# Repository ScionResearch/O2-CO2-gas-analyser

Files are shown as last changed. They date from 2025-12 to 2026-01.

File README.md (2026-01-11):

# O2-CO2 Gas Analyser

A precision gas analysis system built on the SAMD21 microcontroller platform, featuring simultaneous O2 and CO2 measurement with temperature-controlled sampling chamber and Modbus RTU communication.

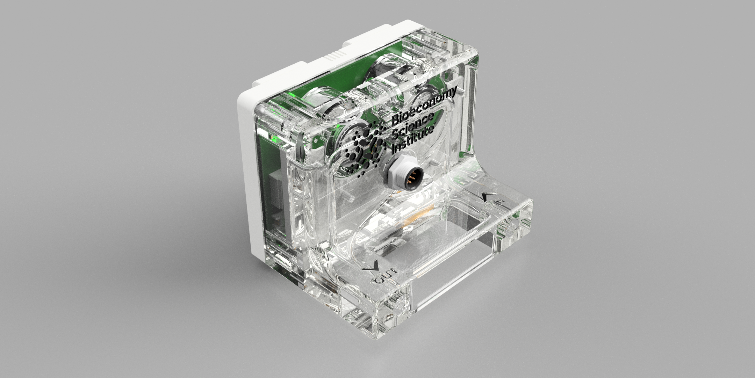
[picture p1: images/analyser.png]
Gas Analyser


## Features

- **O2 Measurement**: SGX 4OX electrochemical oxygen sensor with temperature compensation
- **CO2 Measurement**: SGX INIR2-CD100 infrared CO2 sensor (0-10% range)
- **Temperature Control**: PID-controlled heater maintaining stable measurement conditions
- **Humidity Sensing**: Sensirion SHT4x for gas temperature and relative humidity
- **Communication**: Modbus RTU over RS-485 with configurable baud rate and addressing
- **Status Monitoring**: Comprehensive status register for system health monitoring
- **Calibration**: In-field zero and span calibration for both O2 and CO2 sensors

## Hardware

- **MCU**: SAMD21-based custom board (gas_analyser_m0)
- **O2 Sensor**: SGX 4OX (galvanic cell, 70-130 uA in air)
- **CO2 Sensor**: SGX INIR2-CD100 (NDIR, UART interface)
- **Temperature/Humidity**: Sensirion SHT40
- **Heater**: PWM-controlled with NTC thermistor feedback
- **Interface**: RS-485 with optional 120 Ohm termination

---

## Modbus RTU Interface

### Default Communication Settings

| Parameter | Default Value |
|---|---|
| Slave ID | 100 |
| Baud Rate | 9600 |
| Data Bits | 8 |
| Parity | None |
| Stop Bits | 1 |

### Supported Function Codes

| Function Code | Description |
|---|---|
| 03 | Read Holding Registers |
| 04 | Read Input Registers |
| 06 | Write Single Holding Register |
| 16 | Write Multiple Holding Registers |

---

## Register Definitions

### Input Registers (Function Code 04) - Read Only

Input registers contain sensor measurements. All floating-point values are stored as IEEE 754 single-precision (32-bit) spanning two consecutive 16-bit registers in big-endian order.

| Address | Name | Type | Unit | Description |
|---|---|---|---|---|
| 0-1 | O2percent | float | % | Oxygen concentration |
| 2-3 | CO2percent | float | % | CO2 concentration (as percentage) |
| 4-5 | CO2ppm | float | ppm | CO2 concentration (as ppm) |
| 6-7 | gasTempC | float | C | Gas stream temperature (SHT40) |
| 8-9 | gasRH | float | %RH | Gas stream relative humidity |
| 10-11 | gasAH | float | g/m3 | Absolute humidity |
| 12-13 | gasVP | float | Pa | Vapour pressure |
| 14-15 | ambTempC | float | C | Ambient temperature (NTC) |
| 16-17 | heatTempC | float | C | Heater block temperature (NTC) |

### Holding Registers (Function Code 03/06/16) - Read/Write

Holding registers contain configuration and calibration parameters. Changes are automatically saved to non-volatile memory.

| Address | Name | Type | Unit | Description |
|---|---|---|---|---|
| 0-1 | status | uint32 | - | System status register (see below) |
| 2 | modbusSlaveID | uint16 | - | Modbus slave address (2-246) |
| 3 | modbusBaudrate | uint16 | x10 | Baud rate / 10 (e.g., 960 = 9600) |
| 4 | modbusStopBits | uint16 | - | Stop bits (1-3) |
| 5 | modbusParity | uint16 | - | Parity: 1=Even, 2=Odd, 3=None |
| 6 | modbus120Rterm | uint16 | - | RS-485 termination: 0=Off, 1=On |
| 7 | reserved1 | uint16 | - | Reserved for future use |
| 8 | O2SetZeroPoint | uint16 | - | Write 1 to start O2 zero cal |
| 9 | CO2SetZeroPoint | uint16 | ppm | CO2 zero cal reference (1-4999) |
| 10-11 | O2SetXPoint | float | % | O2 span cal point (10.0-25.0) |
| 12-13 | CO2SetXPoint | float | ppm | CO2 span cal point (300-50000) |
| 14-15 | heaterKp | float | - | PID proportional gain |
| 16-17 | heaterKi | float | - | PID integral gain |
| 18-19 | heaterKd | float | - | PID derivative gain |
| 20-21 | heaterMaxI | float | - | PID integral limit (0-255) |
| 22-23 | heaterSetpointC | float | C | Heater setpoint (20.0-50.0) |
| 24-25 | heaterMinAmbientDeltaC | float | C | Min delta above ambient (0-20) |

#### Valid Baud Rate Values

| Register Value | Actual Baud Rate |
|---|---|
| 960 | 9600 |
| 1920 | 19200 |
| 3840 | 38400 |
| 5760 | 57600 |
| 11520 | 115200 |

---

## Status Register

The status register (holding registers 0-1) is a 32-bit value containing system health information. Each 4-bit nibble represents a different subsystem.

### Status Register Bit Layout

```
Bits 31-24       23-20      19-16               15-12       11-8          7-4    3-0
     [WDT Count] [Amb Temp] [Gas Temp/Humidity] [Heater]    [CO2 Sensor]  [O2]   [System]
```

### Subsystem Status Definitions

#### System Status (Bits 3-0)
| Value | Meaning |
|---|---|
| 0x01 | System OK |
| 0x02 | WDT Reset Occurred |
| 0x03 | System OK + WDT Reset History |

#### O2 Sensor Status (Bits 7-4)
| Value | Meaning |
|---|---|
| 0x01 | Sensor OK |
| 0x02 | Reading too high (>25%) |
| 0x04 | Sensor not connected (<1%) |

#### CO2 Sensor Status (Bits 11-8)
| Value | Meaning |
|---|---|
| 0x01 | Sensor OK |
| 0x02 | Sensor not connected (no data) |
| 0x04 | Sensor communication error |

#### Heater Status (Bits 15-12)
| Value | Meaning |
|---|---|
| 0x01 | Temperature stable |
| 0x02 | Temperature unstable (>0.2C from setpoint) |
| 0x04 | Temperature sensor error |

#### Gas Temperature/Humidity Status (Bits 19-16)
| Value | Meaning |
|---|---|
| 0x01 | Sensor OK |
| 0x02 | Sensor error |

#### Ambient Temperature Status (Bits 23-20)
| Value | Meaning |
|---|---|
| 0x01 | Sensor OK |
| 0x02 | Sensor error |

#### WDT Reset Count (Bits 27-24)
Contains the number of watchdog timer resets since last EEPROM clear (0-255, saturates at 255).

---

## Usage Examples

### Reading Sensor Values (Python with pymodbus)

```python
from pymodbus.client import ModbusSerialClient
import struct

# Connect to the analyser
client = ModbusSerialClient(
    port='COM3',
    baudrate=9600,
    parity='N',
    stopbits=1,
    bytesize=8,
    timeout=1
)
client.connect()

SLAVE_ID = 100

def read_float(client, address, slave_id):
    """Read a 32-bit float from two consecutive input registers."""
    result = client.read_input_registers(address, 2, slave=slave_id)
    if result.isError():
        return None
    # Combine two 16-bit registers into a 32-bit float (big-endian)
    raw = (result.registers[0] << 16) | result.registers[1]
    return struct.unpack('>f', struct.pack('>I', raw))[0]

# Read all sensor values
o2_percent = read_float(client, 0, SLAVE_ID)
co2_percent = read_float(client, 2, SLAVE_ID)
co2_ppm = read_float(client, 4, SLAVE_ID)
gas_temp = read_float(client, 6, SLAVE_ID)
gas_rh = read_float(client, 8, SLAVE_ID)
heater_temp = read_float(client, 16, SLAVE_ID)

print(f"O2: {o2_percent:.2f}%")
print(f"CO2: {co2_ppm:.0f} ppm ({co2_percent:.3f}%)")
print(f"Gas Temperature: {gas_temp:.1f}C")
print(f"Gas RH: {gas_rh:.1f}%")
print(f"Heater Temperature: {heater_temp:.1f}C")

client.close()
```

### Parsing the Status Register

```python
def parse_status(client, slave_id):
    """Read and parse the status register."""
    result = client.read_holding_registers(0, 2, slave=slave_id)
    if result.isError():
        return None
    
    status = (result.registers[0] << 16) | result.registers[1]
    
    # Extract each nibble
    system_status = status & 0x0F
    o2_status = (status >> 4) & 0x0F
    co2_status = (status >> 8) & 0x0F
    heater_status = (status >> 12) & 0x0F
    gas_th_status = (status >> 16) & 0x0F
    amb_temp_status = (status >> 20) & 0x0F
    wdt_count = (status >> 24) & 0xFF
    
    # Interpret statuses
    status_names = {
        'system': {0x01: 'OK', 0x02: 'WDT Reset', 0x03: 'OK (WDT history)'},
        'o2': {0x01: 'OK', 0x02: 'Too High', 0x04: 'Not Connected'},
        'co2': {0x01: 'OK', 0x02: 'Not Connected', 0x04: 'Error'},
        'heater': {0x01: 'Stable', 0x02: 'Unstable', 0x04: 'Sensor Error'},
        'gas_th': {0x01: 'OK', 0x02: 'Error'},
        'amb_temp': {0x01: 'OK', 0x02: 'Error'}
    }
    
    print(f"System: {status_names['system'].get(system_status, 'Unknown')}")
    print(f"O2 Sensor: {status_names['o2'].get(o2_status, 'Unknown')}")
    print(f"CO2 Sensor: {status_names['co2'].get(co2_status, 'Unknown')}")
    print(f"Heater: {status_names['heater'].get(heater_status, 'Unknown')}")
    print(f"Gas Temp/RH: {status_names['gas_th'].get(gas_th_status, 'Unknown')}")
    print(f"Ambient Temp: {status_names['amb_temp'].get(amb_temp_status, 'Unknown')}")
    print(f"WDT Reset Count: {wdt_count}")
    
    return status

parse_status(client, SLAVE_ID)
```

### Writing Configuration (Changing Heater Setpoint)

```python
def write_float(client, address, value, slave_id):
    """Write a 32-bit float to two consecutive holding registers."""
    # Pack float as big-endian 32-bit
    raw = struct.unpack('>I', struct.pack('>f', value))[0]
    high_word = (raw >> 16) & 0xFFFF
    low_word = raw & 0xFFFF
    
    # Write both registers
    result = client.write_registers(address, [high_word, low_word], slave=slave_id)
    return not result.isError()

# Set heater setpoint to 40C
if write_float(client, 21, 40.0, SLAVE_ID):
    print("Heater setpoint updated to 40C")
else:
    print("Failed to update heater setpoint")
```

### Changing Modbus Settings

```python
# Change slave ID to 50
client.write_register(2, 50, slave=SLAVE_ID)

# Change baud rate to 19200 (write 1920 = 19200/10)
client.write_register(3, 1920, slave=SLAVE_ID)

# Enable 120 Ohm termination
client.write_register(6, 1, slave=SLAVE_ID)

# Note: After changing communication settings, 
# you will need to reconnect with the new parameters
```

---

## Calibration Procedures

### O2 Sensor Calibration

The O2 sensor supports two-point calibration: zero (0% O2) and span (typically 20.9% in air).

#### Zero Calibration (0% O2)

1. Flow nitrogen or other zero-O2 gas through the sensor
2. Wait for readings to stabilise
3. Write `1` to register 7 (`O2SetZeroPoint`)

```python
# Start O2 zero calibration
client.write_register(7, 1, slave=SLAVE_ID)
# Calibration takes up to 60 seconds
# Monitor status - system enters STATE_CALIBRATING_O2
```

#### Span Calibration (e.g., 20.9% O2)

1. Flow calibration gas (e.g., ambient air at 20.9% O2)
2. Wait for readings to stabilise
3. Write the known O2 percentage as a float to registers 8-9

```python
# Calibrate with 20.9% O2 (ambient air)
write_float(client, 8, 20.9, SLAVE_ID)
# Calibration takes up to 60 seconds
```

**Calibration Requirements:**
- Sensor current must be within 70-130 uA for air
- Reading must stabilise (+/-0.1 uA for 5 consecutive readings)
- Maximum calibration time: 60 seconds

### CO2 Sensor Calibration

#### Zero Calibration

1. Flow nitrogen or zero-CO2 gas through the sensor
2. Wait for readings to stabilise
3. Write the expected zero reading (typically 0-400 ppm) to register 10

```python
# Set CO2 zero point (expects 0 ppm, sensor reads 50 ppm)
# Write 50 to offset the reading
client.write_register(10, 50, slave=SLAVE_ID)
```

#### Span Calibration

Span calibration for CO2 is reserved for future implementation (registers 11-12).

---

## LED Status Indicator

The analyser has an RGB LED that indicates system state:

| Colour | Pattern | State |
|---|---|---|
| Green | 1 Hz blink | Normal operation |
| Magenta | 1 Hz blink | Startup |
| Amber | 0.5 Hz blink | Temperature unstable |
| Blue | 0.5 Hz blink | O2 calibration in progress |
| Red | 0.5 Hz blink | Error condition |

---

## Building and Flashing

This project uses PlatformIO. To build and upload:

```bash
# Build
pio run

# Upload via Atmel-ICE
pio run --target upload
```

### Dependencies

All libraries are included in the `lib/` folder:
- Adafruit NeoPixel ZeroDMA
- Sensirion I2C SHT4x
- FlashStorage SAMD
- Custom libraries: SGX_4OX, SGX_INIR2_CD100, NTC_Therm, PID_Control, modbus-rtu-slave

---

## Troubleshooting

### No Modbus Response
- Check RS-485 wiring (A/B polarity)
- Verify baud rate and slave ID
- Check termination resistor setting if at end of bus

### O2 Reading Shows 0%
- Check O2 sensor connection
- Verify sensor current is within range (status register)
- Sensor may need replacement if current is <70 uA in air

### Temperature Unstable (Amber LED)
- Allow 5+ minutes for heater to stabilise after power-on
- Check ambient temperature is not too close to setpoint
- Verify heater NTC is properly installed

### CO2 Sensor Not Responding
- Check UART connection (38400 baud)
- Verify sensor is powered and warmed up
- Check status register for sensor errors

---

## License

This project is provided as-is for reference and educational purposes.

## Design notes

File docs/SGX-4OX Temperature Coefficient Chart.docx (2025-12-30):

SGX-OX EC oxygen sensor temperature effects

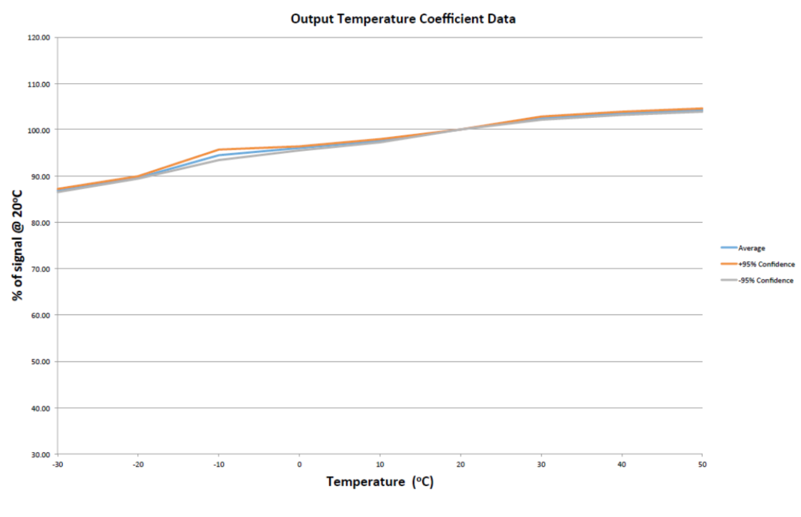
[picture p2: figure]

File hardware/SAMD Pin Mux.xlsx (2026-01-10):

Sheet: SAMD2xx
SAMD2x Pin Multiplex Table
Datasheet: | SAM-D21-DA1-Family-Data-Sheet-DS40001882H.pdf
Application |  |  |  | Variant | Pin | I/O Pin | Supply | A | B |  |  |  |  | C | D | E | F | G | H | Arduino Framework Code
Pin Name | Function | Pin mode | Pin init state | Arduino Pin | SAMD2xE | Port Pin | VDD | EIC | REF | ADC | AC | PTC | DAC | SERCOM | SERCOM-ALT | TC/TCC | TCC | COM | AC/GCLK | Pin #defines | Pinmode() | digitalWrite()
XIN32 |  | Input | Hi Z | 0 | 1 | PA00 | VDDANA | EXTINT.0 |  |  |  |  |  |  | SERCOM1.0 | TCC2/WO.0 |  |  |  | #define PIN_XIN32 0 | pinMode(PIN_XIN32, INPUT);
XOUT32 |  | Input | Hi Z | 1 | 2 | PA01 | VDDANA | EXTINT.1 |  |  |  |  |  |  | SERCOM1.1 | TCC2/WO.1 |  |  |  | #define PIN_XOUT32 1 | pinMode(PIN_XOUT32, INPUT);
VPSU_FB |  |  |  | 2 | 3 | PA02 | VDDANA | EXTINT.2 |  | AIN.0 |  | Y.0 | VOUT |  |  |  | TCC3/WO.0 |  |  | #define PIN_VPSU_FB 2 | pinMode(PIN_VPSU_FB, OUTPUT);
VREF |  |  |  | 3 | 4 | PA03 | VDDANA | EXTINT.3 | ADC/VREFA DAC/VREFA | AIN.1 |  | Y.1 |  |  |  |  | TCC3/WO.1 |  |  | #define PIN_VREF 3 | pinMode(PIN_VREF, OUTPUT);
 |  |  |  |  |  | PB04 | VDDANA | EXTINT.4 |  | AIN.12 |  | Y.10
 |  |  |  |  |  | PB05 | VDDANA | EXTINT.5 |  | AIN.13 |  | Y.11
 |  |  |  |  |  | PB06 | VDDANA | EXTINT.6 |  | AIN.14 |  | Y.12
 |  |  |  |  |  | PB07 | VDDANA | EXTINT.7 |  | AIN.15 |  | Y.13
 |  |  |  |  |  | PB08 | VDDANA | EXTINT.8 |  | AIN.2 |  | Y.14 |  |  | SERCOM4.0 | TC4/WO.0 | TCC3/WO.6
 |  |  |  |  |  | PB09 | VDDANA | EXTINT.9 |  | AIN.3 |  | Y.15 |  |  | SERCOM4.1 | TC4/WO.1 | TCC3/WO.7
NTC_HEAT |  |  |  | 4 | 5 | PA04 | VDDANA | EXTINT.4 | ADC/VREFB | AIN.4 | AIN.0 | Y.2 |  |  | SERCOM0.0 | TCC0/WO.0 | TCC3/WO.2 |  |  | #define PIN_NTC_HEAT 4 | pinMode(PIN_NTC_HEAT, OUTPUT);
NTC_AMB |  |  |  | 5 | 6 | PA05 | VDDANA | EXTINT.5 |  | AIN.5 | AIN.1 | Y.3 |  |  | SERCOM0.1 | TCC0/WO.1 | TCC3/WO.3 |  |  | #define PIN_NTC_AMB 5 | pinMode(PIN_NTC_AMB, OUTPUT);
V_O2_SENS |  |  |  | 6 | 7 | PA06 | VDDANA | EXTINT.6 |  | AIN.6 | AIN.2 | Y.4 |  |  | SERCOM0.2 | TCC1/WO.0 | TCC3/WO.4 |  |  | #define PIN_V_O2_SENS 6 | pinMode(PIN_V_O2_SENS, OUTPUT);
RS485_TERM |  |  |  | 7 | 8 | PA07 | VDDANA | EXTINT.7 |  | AIN.7 | AIN.3 | Y.5 |  |  | SERCOM0.3 | TCC1/WO.1 | TCC3/WO.5 | I2S/SD.0 |  | #define PIN_RS485_TERM 7 | pinMode(PIN_RS485_TERM, OUTPUT);
RS485_TX |  |  |  | 8 | 11 | PA08 | VDDIO | NMI |  | AIN.16 |  | X.0 |  | SERCOM0.0 | SERCOM2.0 | TCC0/WO.0 | TCC1/WO.2 | I2S/SD.1 |  | #define PIN_RS485_TX 8 | pinMode(PIN_RS485_TX, OUTPUT);
RS485_RX |  |  |  | 9 | 12 | PA09 | VDDIO | EXTINT.9 |  | AIN.17 |  | X.1 |  | SERCOM0.1 | SERCOM2.1 | TCC0/WO.1 | TCC1/WO.3 | I2S/MCK.0 |  | #define PIN_RS485_RX 9 | pinMode(PIN_RS485_RX, OUTPUT);
RS485_DE |  |  |  | 10 | 13 | PA10 | VDDIO | EXTINT.10 |  | AIN.18 |  | X.2 |  | SERCOM0.2 | SERCOM2.2 | TCC1/WO.0 | TCC0/WO.2 | I2S/SCK.0 | GCLK_IO.4 | #define PIN_RS485_DE 10 | pinMode(PIN_RS485_DE, OUTPUT);
HEAT_PWM |  |  |  | 11 | 14 | PA11 | VDDIO | EXTINT.11 |  | AIN.19 |  | X.3 |  | SERCOM0.3 | SERCOM2.3 | TCC1/WO.1 | TCC0/WO.3 | I2S/FS.0 | GCLK_IO.5 | #define PIN_HEAT_PWM 11 | pinMode(PIN_HEAT_PWM, OUTPUT);
 |  |  |  |  |  | PB10 | VDDIO | EXTINT.10 |  |  |  |  |  |  | SERCOM4.2 | TC5/WO.0 | TCC0/WO.4 | I2S/MCK.1 | GCLK_IO.4
 |  |  |  |  |  | PB11 | VDDIO | EXTINT.11 |  |  |  |  |  |  | SERCOM4.3 | TC5/WO.1 | TCC0/WO.5 | I2S/SCK.1 | GCLK_IO.5
 |  |  |  |  |  | PB12 | VDDIO | EXTINT.12 |  |  |  | X.12 |  | SERCOM4.0 |  | TC4/WO.0 | TCC0/WO.6 | I2S/FS.1 | GCLK_IO.6
 |  |  |  |  |  | PB13 | VDDIO | EXTINT.13 |  |  |  | X.13 |  | SERCOM4.1 |  | TC4/WO.1 | TCC0/WO.7 |  | GCLK_IO.7
 |  |  |  |  |  | PB14 | VDDIO | EXTINT.14 |  |  |  | X.14 |  | SERCOM4.2 |  | TC5/WO.0 |  |  | GCLK_IO.0
 |  |  |  |  |  | PB15 | VDDIO | EXTINT.15 |  |  |  | X.15 |  | SERCOM4.3 |  | TC5/WO.1 |  |  | GCLK_IO.1
 |  |  |  |  |  | PA12 | VDDIO | EXTINT.12 |  |  |  |  |  | SERCOM2.0 | SERCOM4.0 | TCC2/WO.0 | TCC0/WO.6 |  | AC/CMP.0
 |  |  |  |  |  | PA13 | VDDIO | EXTINT.13 |  |  |  |  |  | SERCOM2.1 | SERCOM4.1 | TCC2/WO.1 | TCC0/WO.7 |  | AC/CMP.1
LED_DAT |  |  |  | 14 | 15 | PA14 | VDDIO | EXTINT.14 |  |  |  |  |  | SERCOM2.2 | SERCOM4.2 | TC3/WO.0 | TCC0/WO.4 |  | GCLK_IO.0 | #define PIN_LED_DAT 14 | pinMode(PIN_LED_DAT, OUTPUT);
 |  |  |  | 15 | 16 | PA15 | VDDIO | EXTINT.15 |  |  |  |  |  | SERCOM2.3 | SERCOM4.3 | TC3/WO.1 | TCC0/WO.5 |  | GCLK_IO.1
UART_CO2_TX |  |  |  | 16 | 17 | PA16 | VDDIO | EXTINT.0 |  |  |  | X.4 |  | SERCOM1.0 | SERCOM3.0 | TCC2/WO.0 | TCC0/WO.6 |  | GCLK_IO.2 | #define PIN_UART_CO2_TX 16 | pinMode(PIN_UART_CO2_TX, OUTPUT);
UART_CO2_RX |  |  |  | 17 | 18 | PA17 | VDDIO | EXTINT.1 |  |  |  | X.5 |  | SERCOM1.1 | SERCOM3.1 | TCC2/WO.1 | TCC0/WO.7 |  | GCLK_IO.3 | #define PIN_UART_CO2_RX 17 | pinMode(PIN_UART_CO2_RX, OUTPUT);
 |  |  |  | 18 | 19 | PA18 | VDDIO | EXTINT.2 |  |  |  | X.6 |  | SERCOM1.2 | SERCOM3.2 | TC3/WO.0 | TCC0/WO.2 |  | AC/CMP.0
 |  |  |  | 19 | 20 | PA19 | VDDIO | EXTINT.3 |  |  |  | X.7 |  | SERCOM1.3 | SERCOM3.3 | TC3/WO.1 | TCC0/WO.3 | I2S/SD.0 | AC/CMP.1
 |  |  |  |  |  | PB16 | VDDIO | EXTINT.0 |  |  |  |  |  | SERCOM5.0 |  | TC6/WO.0 | TCC0/WO.4 | I2S/SD.1 | GCLK_IO.2
 |  |  |  |  |  | PB17 | VDDIO | EXTINT.1 |  |  |  |  |  | SERCOM5.1 |  | TC6/WO.1 | TCC0/WO.5 | I2S/MCK.0 | GCLK_IO.3
 |  |  |  |  |  | PA20 | VDDIO | EXTINT.4 |  |  |  | X.8 |  | SERCOM5.2 | SERCOM3.2 | TC7/WO.0 | TCC0/WO.6 | I2S/SCK.0 | GCLK_IO.4
 |  |  |  |  |  | PA21 | VDDIO | EXTINT.5 |  |  |  | X.9 |  | SERCOM5.3 | SERCOM3.3 | TC7/WO.1 | TCC0/WO.7 | I2S/FS.0 | GCLK_IO.5
I2C_SDA |  |  |  | 22 | 21 | PA22 | VDDIO | EXTINT.6 |  |  |  | X.10 |  | SERCOM3.0 | SERCOM5.0 | TC4/WO.0 | TCC0/WO.4 |  | GCLK_IO.6 | #define PIN_I2C_SDA 22 | pinMode(PIN_I2C_SDA, OUTPUT);
I2C_SCL |  |  |  | 23 | 22 | PA23 | VDDIO | EXTINT.7 |  |  |  | X.11 |  | SERCOM3.1 | SERCOM5.1 | TC4/WO.1 | TCC0/WO.5 | USB/SOF 1kHz | GCLK_IO.7 | #define PIN_I2C_SCL 23 | pinMode(PIN_I2C_SCL, OUTPUT);
USB_DM |  |  |  | 24 | 23 | PA24 | VDDIO | EXTINT.12 |  |  |  |  |  | SERCOM3.2 | SERCOM5.2 | TC5/WO.0 | TCC1/WO.2 | USB/DM |  | #define PIN_USB_DM 24 | pinMode(PIN_USB_DM, OUTPUT);
USB_DP |  |  |  | 25 | 24 | PA25 | VDDIO | EXTINT.13 |  |  |  |  |  | SERCOM3.3 | SERCOM5.3 | TC5/WO.1 | TCC1/WO.3 | USB/DP |  | #define PIN_USB_DP 25 | pinMode(PIN_USB_DP, OUTPUT);
 |  |  |  |  |  | PB22 | VDDIO | EXTINT.6 |  |  |  |  |  |  | SERCOM5.2 | TC7/WO.0 | TCC3/WO.0 |  | GCLK_IO.0
 |  |  |  |  |  | PB23 | VDDIO | EXTINT.7 |  |  |  |  |  |  | SERCOM5.3 | TC7/WO.1 | TCC3/WO.1 |  | GCLK_IO.1
 |  |  |  | 27 | 25 | PA27 | VDDIO | EXTINT.15 |  |  |  |  |  |  |  |  | TCC3/WO.6 |  | GCLK_IO.0
 |  |  |  | 28 | 27 | PA28 | VDDIO | EXTINT.8 |  |  |  |  |  |  |  |  | TCC3/WO.7 |  | GCLK_IO.0
SWCLK |  |  |  | 30 | 31 | PA30 | VDDIO | EXTINT.10 |  |  |  |  |  |  | SERCOM1.2 | TCC1/WO.0 | TCC3/WO.4 | SWCLK | GCLK_IO.0 | #define PIN_SWCLK 30 | pinMode(PIN_SWCLK, OUTPUT);
SWDIO |  |  |  | 31 | 32 | PA31 | VDDIO | EXTINT.11 |  |  |  |  |  |  | SERCOM1.3 | TCC1/WO.1 | TCC3/WO.5 | SWDIO |  | #define PIN_SWDIO 31 | pinMode(PIN_SWDIO, OUTPUT);
 |  |  |  |  |  | PB30 | VDDIO | EXTINT.14 |  |  |  |  |  |  | SERCOM5.0 | TCC0/WO.0 | TCC1/WO.2
 |  |  |  |  |  | PB31 | VDDIO | EXTINT.15 |  |  |  |  |  |  | SERCOM5.1 | TCC0/WO.1 | TCC1/WO.3
 |  |  |  |  |  | PB00 | VDDANA | EXTINT.0 |  | AIN.8 |  | Y.6 |  |  | SERCOM5.2 | TC7/WO.0
 |  |  |  |  |  | PB01 | VDDANA | EXTINT.1 |  | AIN.9 |  | Y.7 |  |  | SERCOM5.3 | TC7/WO.1
 |  |  |  |  |  | PB02 | VDDANA | EXTINT.2 |  | AIN.10 |  | Y.8 |  |  | SERCOM5.0 | TC6/WO.0 | TCC3/WO.2
 |  |  |  |  |  | PB03 | VDDANA | EXTINT.3 |  | AIN.11 |  | Y.9 |  |  | SERCOM5.1 | TC6/WO.1 | TCC3/WO.3
 |  |  |  |  |  |  |  |  |  |  |  |  |  |  |  |  |  |  |  | SPI pinout options:
 |  |  |  |  |  |  |  |  |  |  |  |  |  |  |  |  |  |  |  | MOSI & SCK | MISO (any pad)
 |  |  |  |  |  |  |  |  |  |  |  |  |  |  |  |  |  |  |  | SPI_PAD_0_SCK_1 | SERCOM_RX_PAD_0
 |  |  |  |  |  |  |  |  |  |  |  |  |  |  |  |  |  |  |  | SPI_PAD_2_SCK_3 | SERCOM_RX_PAD_1
 |  |  |  |  |  |  |  |  |  |  |  |  |  |  |  |  |  |  |  | SPI_PAD_3_SCK_1 | SERCOM_RX_PAD_2
 |  |  |  |  |  |  |  |  |  |  |  |  |  |  |  |  |  |  |  | SPI_PAD_0_SCK_3 | SERCOM_RX_PAD_3

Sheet: Lists
Pin mode | Output state
Input | High
Output | Low
Output Analogue | Hi Z

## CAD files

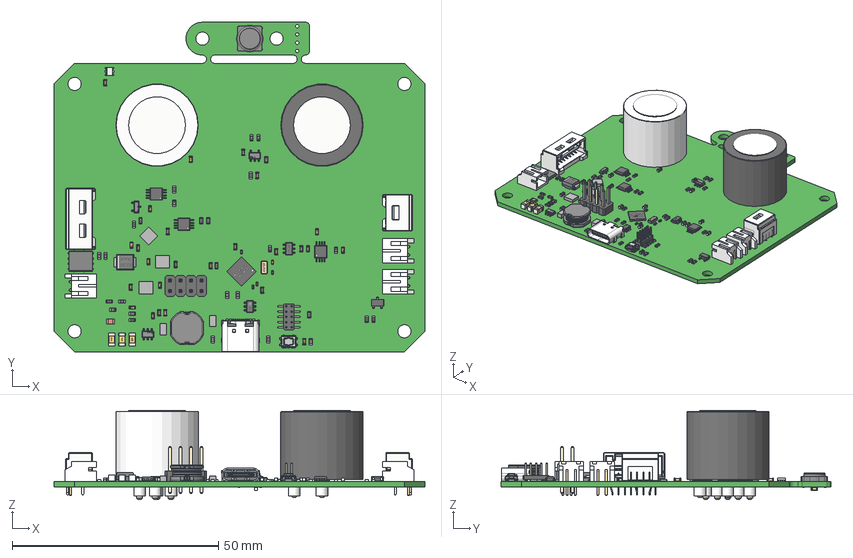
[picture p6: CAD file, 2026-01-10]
hardware/Gas Analyser O2 CO2.step
90.0 x 80.0 x 21.6 mm
H01-0023_00
H01-0032_00
SHT4X-1
0603_CAP x 26
0603_RES x 28
ABS07
USB_type_C_smd_12p-GT-USB-7010ASV
8P MSOP x 3
32P QFN - ATSAMD21E17A
BODY-SOT x 2
LEAD-SOT x 11
Texas Logo Yury
Texas Logo Yury - Copy
SOT-6 x 2
1.5mm Open Bottom Contact 15111-81-3920 v1 x 8
Extruded x 7
Texas Logo
Texas Logo - 1
Panasonic Logo
SOT-23
Coupound
LDF
WS2812-2020
0803_LED
User Library-Inductor SRN8040 Series
4P MOLEX Clik-MATE 1.5mm 5031750400
8P DIP Male Header 2.54mm
8P MOLEX Clik-MATE 1.5mm 5031750800
2P 2mm RA JST S2B-PH-K-S x 3
10P 1.27mm Header SMD
Bourns Logo
SMBJ Transil
0402 CAP x 5
1206_CAP x 3

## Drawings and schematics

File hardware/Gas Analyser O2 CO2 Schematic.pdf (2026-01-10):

# Power Supplies G

USB interface | I/O ¹ ¹ I/O ² ³ I/O ³ ⁴ I/O ⁴ ⁶ | V⁺

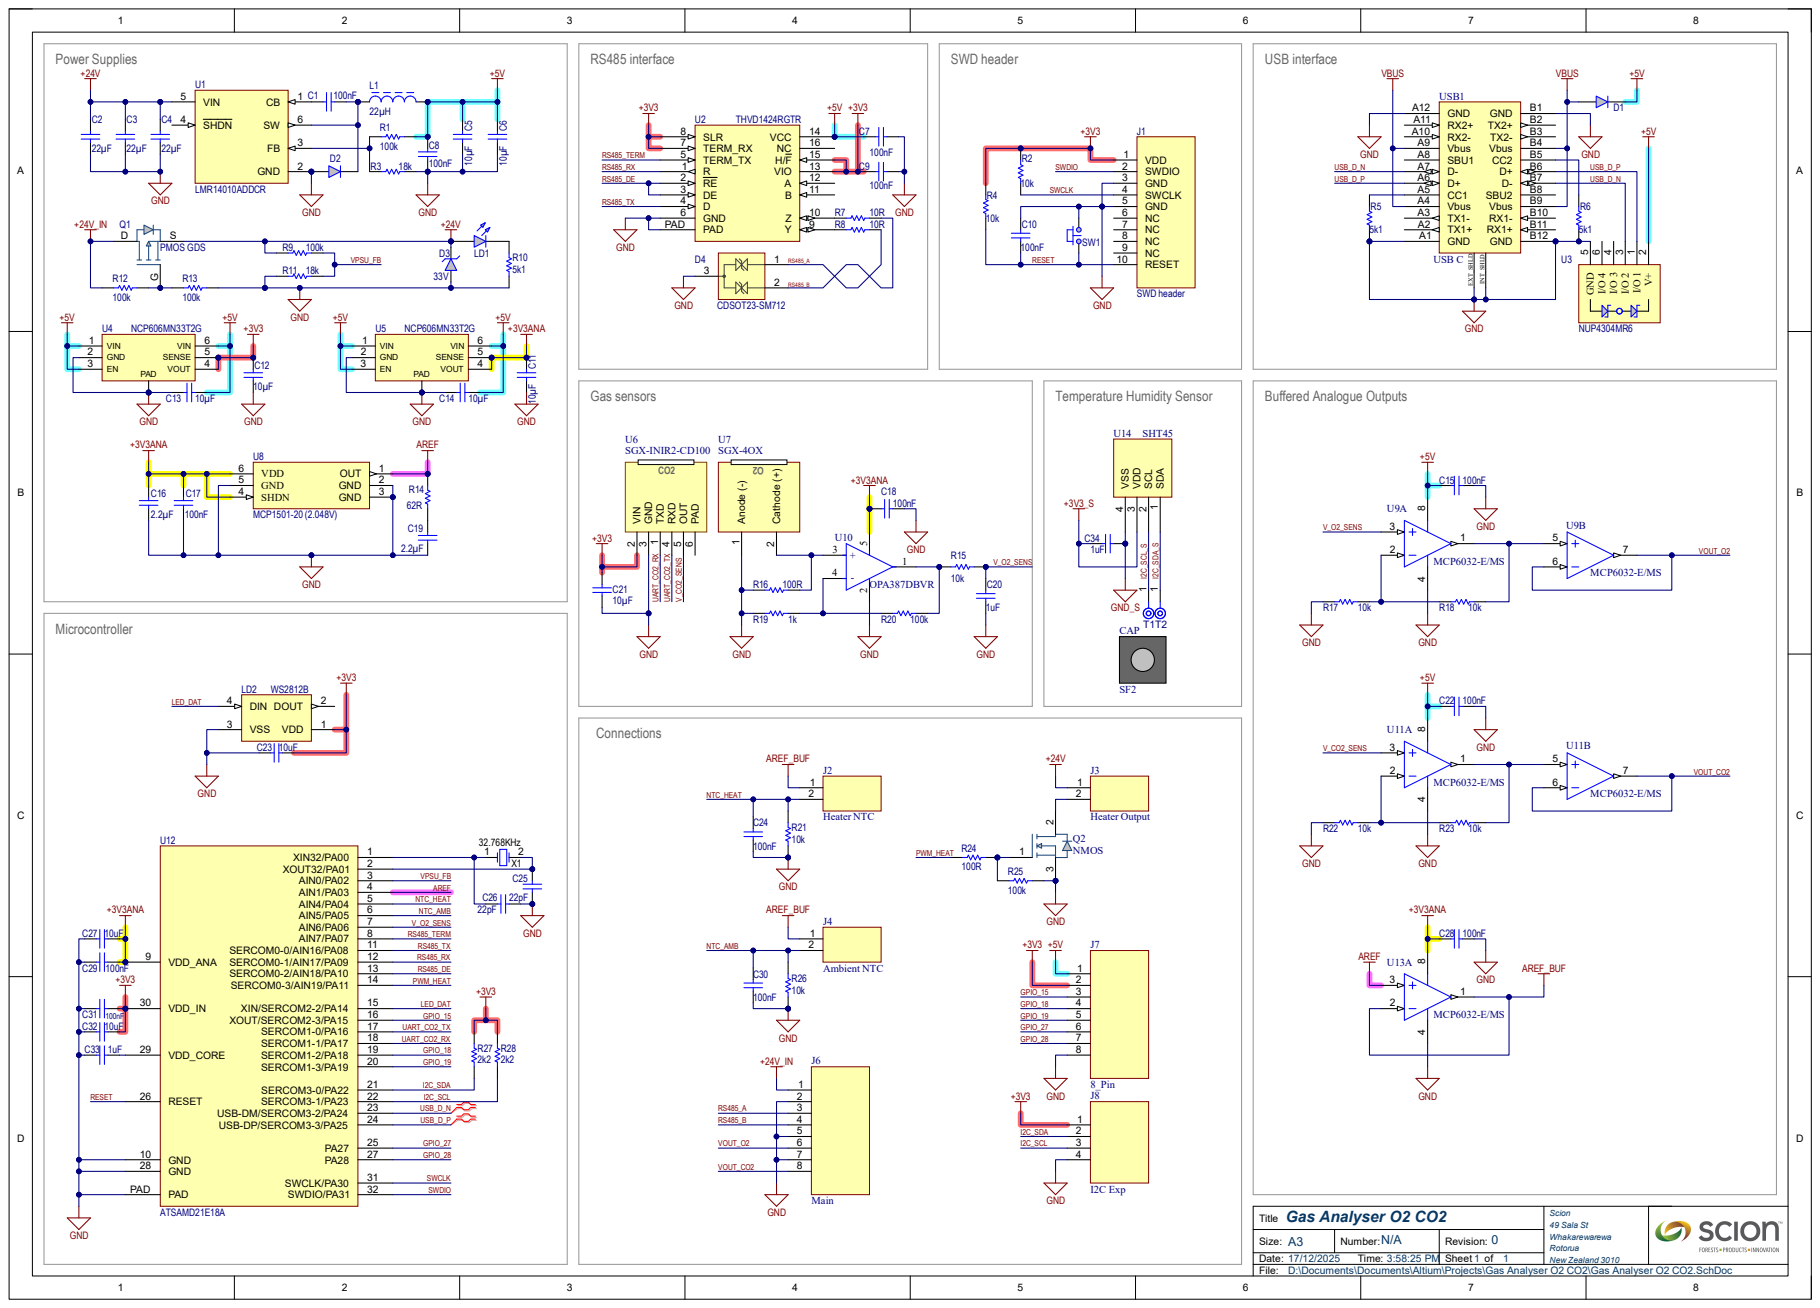
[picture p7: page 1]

Temperature Humidity Sensor SDA

Gas Analyser O2 CO2
Title
D:\Documents\Documents\Altium\Projects\Gas Analyser O2 CO2\Gas Analyser O2 CO2.SchDoc

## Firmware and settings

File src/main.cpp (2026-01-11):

#include "defines.h"
#include "FlashStorage_SAMD.h"

uint32_t slowLoopTimeStamp = 0;
uint32_t mediumLoopTimeStamp = 0;
uint32_t fastLoopTimeStamp = 0;

// Forward declarations
void setLED(uint32_t colour);
void updateLED();
uint16_t serialConfigFromParts(uint8_t parity, uint8_t stopBits, uint8_t dataBits);
void serialConfigToParts(uint16_t config, uint16_t &stopBits, uint16_t &parity, uint16_t &dataBits);
void configToHolding();
bool holdingToConfig();
void sensorsToInputs();
float vapourPressure(float temperatureC, float relativeHumidity);
float absoluteHumidity(float temperatureC, float vapourPressure);
void setErrorState(uint8_t statusItem_bp, uint8_t errorCode_bm);
uint8_t getErrorState(uint8_t statusItem_bp);
bool updateSHTmeasurements();
bool updateAmbientTemp();
bool updateHeaterTemp();
bool updateO2();
bool updateCO2(uint32_t lastReading_ts);


void setup() {
  asm(".global _printf_float");

  Serial.begin(115200);

  systemState.state = STATE_STARTUP;
  // LED init
  led.begin();
  led.clear();
  updateLED();

  uint32_t startTime = millis();
  while (!Serial) {
    delay(100);
    updateLED();
    if (millis() - startTime >= 5000) {
      break;
    }
  }

  // EEPROM init
  uint8_t eepromVersion = EEPROM.read(0);
  if (eepromVersion != EEPROM_VERSION_BYTE) {
    Serial.printf("Got EEPROM version: 0x%0X, expected: 0x%0X\n\r", eepromVersion, EEPROM_VERSION_BYTE);
    Serial.println("Writing EEPROM version...");
    EEPROM.put(0, EEPROM_VERSION_BYTE);
    EEPROM.put(1, config);
    EEPROM.commit();
  } else {
    Serial.printf("Got EEPROM version: 0x%0X\n\r", eepromVersion);
    EEPROM.get(1, config);
    Serial.printf("Got config:\n\r");
    Serial.printf("  modbusBaudrate: %u\n\r", config.modbusBaudrate);
    Serial.printf("  modbusConfig: %u\n\r", config.modbusConfig);
    Serial.printf("  modbusSlaveID: %u\n\r", config.modbusSlaveID);
    Serial.printf("  heaterKp: %.2f\n\r", config.heaterKp);
    Serial.printf("  heaterKi: %.2f\n\r", config.heaterKi);
    Serial.printf("  heaterKd: %.2f\n\r", config.heaterKd);
    Serial.printf("  heaterMaxI: %.2f\n\r", config.heaterMaxI);
    Serial.printf("  heaterSetpointC: %.2f\n\r", config.heaterSetpointC);
    Serial.printf("  heaterMinAmbientDeltaC: %.2f\n\r", config.heaterMinAmbientDeltaC);
    Serial.printf("  o2CalibrationOffset: %.2f\n\r", config.o2CalibrationOffset);
    Serial.printf("  o2CalibrationScale: %.2f\n\r", config.o2CalibrationScale);
    Serial.printf("  co2CalibrationOffset: %d\n\r", config.co2CalibrationOffset);
    Serial.printf("  co2CalibrationScale: %.2f\n\r", config.co2CalibrationScale);
    Serial.printf("  ntcAmbOffsetC: %.2f\n\r", config.ntcAmbOffsetC);
    Serial.printf("  ntcAmbScale: %.2f\n\r", config.ntcAmbScale);
    Serial.printf("  ntcHeatOffsetC: %.2f\n\r", config.ntcHeatOffsetC);
    Serial.printf("  ntcHeatScale: %.2f\n\r", config.ntcHeatScale);
  }

  uint8_t wdtCount = 0;
  if (wdtResetOccurred()) {
    config.wdtTimerResetCounter++;
    if ((config.wdtTimerResetCounter >255)) {
      wdtCount = 255;
    } else wdtCount = (uint8_t)config.wdtTimerResetCounter;
    setErrorState(STATUS_SYSTEM_bp, STATUS_SYSTEM_WDT_RESET_bm);
    EEPROM.put(1, config);
    EEPROM.commit();
  }
  setErrorState(STATUS_WDT_RESETS_bp, wdtCount);
  Serial.printf("Reset reason: %s\n\r", resetReason());
 

  Serial.println("O2-CO2 Gas Analyser Starting...");

  // Analog init
  analogReference(AR_EXTERNAL);
  analogReadResolution(12);
  ntcAmb.begin();
  ntcHeat.begin();
  ntcAmb.setOffset(config.ntcAmbOffsetC);
  ntcAmb.setScale(config.ntcAmbScale);  
  ntcHeat.setOffset(config.ntcHeatOffsetC);
  ntcHeat.setScale(config.ntcHeatScale);
  ntcAmb.enableMovingAverage(NTC_MOVING_AVERAGE_SAMPLES);
  ntcAmb.enableOversampling(NTC_OVERSAMPLING_SAMPLES);
  ntcHeat.enableMovingAverage(NTC_MOVING_AVERAGE_SAMPLES);
  ntcHeat.enableOversampling(NTC_OVERSAMPLING_SAMPLES);

  // O2 sensor init
  O2.begin();
  O2.setZeroCalibration(config.o2CalibrationOffset);
  O2.setSpanCalibration(config.o2CalibrationScale);

  Serial.printf("O2 sensor zero calibration: %.2f\n\r", O2.getZeroCalibration());
  Serial.printf("O2 sensor span calibration: %.2f\n\r", O2.getSpanCalibration());
  Serial.printf("O2: %.2f\n\r", O2.readO2());

  // CO2 sensor init
  CO2.begin();
  CO2.setCalibrationOffset(config.co2CalibrationOffset);
  CO2.setCalibrationScale(config.co2CalibrationScale);

  // SHT4x init
  Wire.begin();
  sht.begin(Wire, SHT40_I2C_ADDR_44);
  sht.softReset();
  uint32_t serialNumber = 0;
  uint16_t error = sht.serialNumber(serialNumber);
  Serial.println("Initialising SHT4x sensor...");
  if (error) {
    char errorMessage[64];
    Serial.print("Error trying to execute serialNumber(): ");
    errorToString(error, errorMessage, sizeof errorMessage);
    Serial.println(errorMessage);
    setLED(LED_RED);
    while (1);
  }
  Serial.print("  serialNumber: ");
  Serial.print(serialNumber);
  Serial.println();

  // Modbus init
  Serial.println("Initialising Modbus...");
  configToHolding();
  modbus.configureHoldingRegisters(holding, NUM_HOLDING_REGISTERS);
  modbus.configureInputRegisters(input, NUM_INPUT_REGISTERS);

  modbus.begin(config.modbusSlaveID,config.modbusBaudrate, config.modbusConfig);
  
  // PID Control init
  Serial.println("Initialising PID controller...");
  heaterCtrl.begin(config.heaterKp, config.heaterKi, config.heaterKd, config.heaterSetpointC);
  heaterCtrl.setOutputLimits(0, 255);
  heaterCtrl.setIntegralLimits(-40, config.heaterMaxI);
  heaterCtrl.setSampleTime(500);
  heaterCtrl.setStaleDataDetection(0.1, 10000);
  heaterCtrl.setSafeValueLimits(0.0, 60.0);
  heaterCtrl.enable();
  heaterCtrl.setIterm(50.0); // Set inital Iterm to stop long wind up times when T is already close to setpoint

  systemState.state = STATE_TEMP_UNSTABLE;
  setErrorState(STATUS_HEATER_bp, STATUS_HEATER_TEMP_UNSTABLE_bm);

  updateLED();

  wdt_init ( WDT_CONFIG_PER_2K );

  Serial.println("Initialisation complete.");
  uint8_t systemStatus = getErrorState(STATUS_SYSTEM_bp) | STATUS_SYSTEM_OK_bm;
  setErrorState(STATUS_SYSTEM_bp, systemStatus);
  
  slowLoopTimeStamp = millis();
  mediumLoopTimeStamp = millis();
  fastLoopTimeStamp = millis();
}


void loop() {
  // Fast loop - every cycle -------------------►►►
  if (millis() - fastLoopTimeStamp >= 50) {
    fastLoopTimeStamp = millis();
    int FC = modbus.poll();
    if (FC > 0) {
      if (FC == 6 || FC == 16) {
        if (holdingToConfig()) {
          static uint32_t lastConfigSave_ts = millis();
          if (millis() - lastConfigSave_ts >= 5000) {
            lastConfigSave_ts = millis();
            Serial.println("Saving config to EEPROM...");
            EEPROM.commit();
          }
        }
      }
    }
    wdt_reset();
    updateLED();
  }

  // ------------------------------------------------|

  static uint32_t lastCO2Reading_ts = 0;

  // Medium loop - every 200ms -----------------------►►
  if (millis() - mediumLoopTimeStamp >= 200) {
    mediumLoopTimeStamp = millis();

    

    // CO2 sensor management
    if (CO2.manage()) {
      lastCO2Reading_ts = millis();
    }

    // O2 sensor calibration management
    static bool O2calibrating = false;
    if (O2.isCalibrating()) {
      if (!O2calibrating) {
        O2calibrating = true;
        systemState.state = STATE_CALIBRATING_O2;
      }    
      O2.manageCalibration();
    } else if (O2calibrating) {
      uint8_t error = O2.calibrationError();
      if (error == 0) {
        Serial.printf("O2 calibration complete, span coefficient: %.2f offset: %.2f\n\r", O2.getSpanCalibration(), O2.getZeroCalibration());
        config.o2CalibrationOffset = O2.getZeroCalibration();
        config.o2CalibrationScale = O2.getSpanCalibration();
        EEPROM.put(1, config);
        EEPROM.commit();
        Serial.println("Saved new values to non-volatile memory");
        systemState.state = STATE_NORMAL;
      } else {
        const char *errorMessage[4] = {"did not stabilise", "current below min", "current above max", "unknown error"};
        if (error > 3) error = 3;
        Serial.printf("O2 calibration error: %s\n\r", errorMessage[error]);
        systemState.state = STATE_ERROR;
      }
      O2calibrating = false;
    }
  }
  // ------------------------------------------------|

  // Slow loop - every 1000ms -----------------------►

  if (millis() - slowLoopTimeStamp >= 1000) {
    slowLoopTimeStamp = millis();
    
    // Sensor reads    
    updateHeaterTemp();
    heaterCtrl.update(modbusInputRegisters.heatTempC);
    updateAmbientTemp();
    updateSHTmeasurements();
    updateO2();
    updateCO2(lastCO2Reading_ts);

    sensorsToInputs();
  }
  // ------------------------------------------------|
}

void setLED(uint32_t colour) {
  led.setPixelColor(0, colour);
  led.show();
}

void updateLED() {
  static uint32_t timeStamp = millis();
  static bool ledState = false;

  if (systemState.state > 4) return;

  uint32_t period = systemState.blinkHz[systemState.state] > 0 ? (500.0 / systemState.blinkHz[systemState.state]) : 0;
  if (millis() - timeStamp >= period) {
    timeStamp = millis();
    if (period == 0) {
      ledState = true;
    } else {
      ledState = !ledState;
    }
    if (ledState) {
      setLED(systemState.colour[systemState.state]);
    } else {
      setLED(0x000000);
    }
  }
}

uint16_t serialConfigFromParts(uint8_t parity, uint8_t stopBits, uint8_t dataBits) {
  // Parity: 0 = None, 1 = Even, 2 = Odd, 3 = None
  // Stop bits: 0 = 1, 1 = 1, 2 = 1.5, 3 = 2
  // Data bits: 0 = 8, 5-8 = 5-8
  if (parity > 3 || stopBits > 3 || dataBits > 8 || (dataBits > 0 && dataBits < 5)) return SERIAL_8N1;
  if (parity == 0) parity = 3;
  if (stopBits == 0) stopBits = 1;
  if (dataBits == 0) dataBits = 8;
  return (parity & 0x03) | ((stopBits & 0x03) << 4) | ((dataBits & 0x0F) << 8);
}

void serialConfigToParts(uint16_t config, uint16_t &stopBits, uint16_t &parity, uint16_t &dataBits) {
  parity = config & 0x03;
  stopBits = (config >> 4) & 0x03;
  dataBits = (config >> 8) & 0x0F;
}

// Copy main config to holding register struct
void configToHolding() {
  modbusHoldingRegisters.modbusSlaveID = config.modbusSlaveID;
  modbusHoldingRegisters.modbusBaudrate = config.modbusBaudrate / 10;
  uint16_t dataBits;
  serialConfigToParts(config.modbusConfig, modbusHoldingRegisters.modbusStopBits, modbusHoldingRegisters.modbusParity, dataBits);
  modbusHoldingRegisters.modbus120Rterm = config.modbus120Rterm;
  modbusHoldingRegisters.heaterKp = config.heaterKp;
  modbusHoldingRegisters.heaterKi = config.heaterKi;
  modbusHoldingRegisters.heaterKd = config.heaterKd;
  modbusHoldingRegisters.heaterMaxI = config.heaterMaxI;
  modbusHoldingRegisters.heaterSetpointC = config.heaterSetpointC;
  modbusHoldingRegisters.heaterMinAmbientDeltaC = config.heaterMinAmbientDeltaC;

  modbusHoldingRegisters.O2SetZeroPoint = 0;
  modbusHoldingRegisters.O2SetXPoint = 0;
  modbusHoldingRegisters.CO2SetZeroPoint = 0;
  modbusHoldingRegisters.CO2SetXPoint = 0;

  // Update holding registers array
  memcpy(holding, &modbusHoldingRegisters, sizeof(modbusHoldingRegisters));
}

// Update main config from holding register struct
bool holdingToConfig() {
  bool configToSave = false;
  bool reinitModbus = false;
  bool serialConfigChanged = false;
  ModbusHoldingRegisters temp;
  memcpy(&temp, holding, sizeof(temp));

  // Modbus settings
  if (temp.modbusSlaveID != modbusHoldingRegisters.modbusSlaveID) {
    if (temp.modbusSlaveID > 1 && temp.modbusSlaveID < 247) {
      modbusHoldingRegisters.modbusSlaveID = temp.modbusSlaveID;
      config.modbusSlaveID = temp.modbusSlaveID;
      configToSave = true;
      reinitModbus = true;
      Serial.printf("Modbus slave ID changed to %u\n\r", temp.modbusSlaveID);
    }
  }
  if (temp.modbusBaudrate != modbusHoldingRegisters.modbusBaudrate) {
    if (   temp.modbusBaudrate == 960 // Baudrate stored as 1 tenth to fit inside uint16
        || temp.modbusBaudrate == 1920
        || temp.modbusBaudrate == 3840
        || temp.modbusBaudrate == 5760
        || temp.modbusBaudrate == 11520) {
      
      modbusHoldingRegisters.modbusBaudrate = temp.modbusBaudrate;
      config.modbusBaudrate = temp.modbusBaudrate * 10;
      configToSave = true;
      reinitModbus = true;
      Serial.printf("Modbus baudrate changed to %u\n\r", temp.modbusBaudrate * 10);
    }    
  }
  if (temp.modbusParity != modbusHoldingRegisters.modbusParity) {
    if (temp.modbusParity > 0 && temp.modbusParity < 4) {
      modbusHoldingRegisters.modbusParity = temp.modbusParity;
      serialConfigChanged = true;
      Serial.printf("Modbus parity changed to %u\n\r", temp.modbusParity);
    }
  }
  if (temp.modbusStopBits != modbusHoldingRegisters.modbusStopBits) {
    if (temp.modbusStopBits > 0 && temp.modbusStopBits < 4) {
      modbusHoldingRegisters.modbusStopBits = temp.modbusStopBits;
      serialConfigChanged = true;
      Serial.printf("Modbus stop bits changed to %u\n\r", temp.modbusStopBits);
    }
  }
  if (serialConfigChanged) {
    config.modbusConfig = serialConfigFromParts(modbusHoldingRegisters.modbusParity, modbusHoldingRegisters.modbusStopBits, 8);
    configToSave = true;
    reinitModbus = true;
    Serial.printf("Modbus config changed to %04X\n\r", config.modbusConfig);
  }
  if (temp.modbus120Rterm != modbusHoldingRegisters.modbus120Rterm) {
    if (temp.modbus120Rterm >= 0 && temp.modbus120Rterm < 2) {
      modbusHoldingRegisters.modbus120Rterm = temp.modbus120Rterm;
      config.modbus120Rterm = temp.modbus120Rterm;
      digitalWrite(PIN_RS485_TERM, (bool)temp.modbus120Rterm);
      configToSave = true;
      Serial.printf("Modbus 120R term changed to %s\n\r", temp.modbus120Rterm ? "temrinated" : "un-terminated");
    }
  }

  // Heater settings
  if (temp.heaterKp != modbusHoldingRegisters.heaterKp) {
    if (temp.heaterKp > 0.0 && temp.heaterKp < 1000.0) {
      modbusHoldingRegisters.heaterKp = temp.heaterKp;
      config.heaterKp = temp.heaterKp;
      configToSave = true;
      Serial.printf("Heater Kp changed to %f\n\r", temp.heaterKp);
    }
  }
  if (temp.heaterKi != modbusHoldingRegisters.heaterKi) {
    if (temp.heaterKi > 0.0 && temp.heaterKi < 1000.0) {
      modbusHoldingRegisters.heaterKi = temp.heaterKi;
      config.heaterKi = temp.heaterKi;
      configToSave = true;
      Serial.printf("Heater Ki changed to %f\n\r", temp.heaterKi);
    }
  }
  if (temp.heaterKd != modbusHoldingRegisters.heaterKd) {
    if (temp.heaterKd > 0.0 && temp.heaterKd < 1000.0) {
      modbusHoldingRegisters.heaterKd = temp.heaterKd;
      config.heaterKd = temp.heaterKd;
      configToSave = true;
      Serial.printf("Heater Kd changed to %f\n\r", temp.heaterKd);
    }
  }
  if (temp.heaterMaxI != modbusHoldingRegisters.heaterMaxI) {
    if (temp.heaterMaxI > 0.0 && temp.heaterMaxI < 255.0) {
      modbusHoldingRegisters.heaterMaxI = temp.heaterMaxI;
      config.heaterMaxI = temp.heaterMaxI;
      configToSave = true;
      Serial.printf("Heater max I changed to %f\n\r", temp.heaterMaxI);
    }
  }
  if (temp.heaterSetpointC != modbusHoldingRegisters.heaterSetpointC) {
    if (temp.heaterSetpointC >= 20.0 && temp.heaterSetpointC <= 50.0) {
      modbusHoldingRegisters.heaterSetpointC = temp.heaterSetpointC;
      config.heaterSetpointC = temp.heaterSetpointC;
      configToSave = true;
      heaterCtrl.setpoint(config.heaterSetpointC);
      Serial.printf("Heater setpoint changed to %f\n\r", temp.heaterSetpointC);  
    }
  }
  if (temp.heaterMinAmbientDeltaC != modbusHoldingRegisters.heaterMinAmbientDeltaC) {
    if (temp.heaterMinAmbientDeltaC >= 0.0 && temp.heaterMinAmbientDeltaC <= 20.0) {
      modbusHoldingRegisters.heaterMinAmbientDeltaC = temp.heaterMinAmbientDeltaC;
      config.heaterMinAmbientDeltaC = temp.heaterMinAmbientDeltaC;
      configToSave = true;
      Serial.printf("Heater min ambient delta changed to %f\n\r", temp.heaterMinAmbientDeltaC);
    }
  }

  // Sensor calibration
  if (temp.O2SetZeroPoint == 1) {
    // Start zero point calibration
    O2.startZeroCalibration(modbusInputRegisters.gasTempC);
    Serial.println("Start O2 zero point calibration");
  }
  if (temp.O2SetXPoint >= 10.0 && temp.O2SetXPoint <= 25.0) {
    // Start high point calibration
    O2.startSpanCalibration(temp.O2SetXPoint, modbusInputRegisters.gasTempC);
    Serial.println("Start O2 high point calibration");
  }
  if (temp.CO2SetZeroPoint > 0 && temp.CO2SetZeroPoint < 5000) {
    // Start zero point calibration
    CO2.setCalibrationOffset(temp.CO2SetZeroPoint - CO2.CO2());
    Serial.println("Start CO2 zero point calibration");
  }
  if (temp.CO2SetXPoint >= 300.0 && temp.CO2SetXPoint <= 50000.0) {
    // Start high point calibration
    // TODO
    Serial.println("Start CO2 high point calibration");
  }

  // Rewrite holding registers array with new (sanitised values)
  memcpy(holding, &modbusHoldingRegisters, sizeof(modbusHoldingRegisters));

  if (reinitModbus) {
    modbus.begin(config.modbusSlaveID, config.modbusBaudrate, config.modbusConfig);
  }

  if (configToSave) {
    EEPROM.put(1, config);
    return true;
  } else {
    return false;
  }
}

void sensorsToInputs() {
  memcpy(input, &modbusInputRegisters, sizeof(modbusInputRegisters));
}

float vapourPressure(float temperatureC, float relativeHumidity) {
  // Saturation vapour pressure (Pa)
  float es = 610.94f * expf((17.625f * temperatureC) / (temperatureC + 243.04f));

  // Actual vapour pressure (Pa)
  return (relativeHumidity / 100.0f) * es;
}

float absoluteHumidity(float temperatureC, float vapourPressure) {
  return (vapourPressure * 1000.0f) / (461.5f * (temperatureC + 273.15f));
}

void setErrorState(uint8_t statusItem_bp, uint8_t errorCode_bm) {
  if (statusItem_bp > 31) return;
  uint32_t statusBits = errorCode_bm << (statusItem_bp);
  modbusHoldingRegisters.status &= ~(0x0F << statusItem_bp); // Clear existing bits
  modbusHoldingRegisters.status |= statusBits;
  memcpy(holding, &modbusHoldingRegisters.status, sizeof(uint32_t));
}

uint8_t getErrorState(uint8_t statusItem_bp) {
  memcpy(&modbusHoldingRegisters.status, holding, sizeof(uint32_t));
  if (statusItem_bp > 31) return 0;
  return (modbusHoldingRegisters.status >> statusItem_bp) & 0x0F;
}

bool updateSHTmeasurements() {
  static bool sensorError = false;
  bool prevSensorError = sensorError;
  uint16_t error = sht.measureHighPrecision(modbusInputRegisters.gasTempC, modbusInputRegisters.gasRH);
  if (error) {
    setErrorState(STATUS_GAS_TEMP_HUMIDITY_bp, STATUS_GAS_TEMP_HUMIDITY_SENOSR_ERROR_bm);
    sensorError = true;
  } else {
    setErrorState(STATUS_GAS_TEMP_HUMIDITY_bp, STATUS_GAS_TEMP_HUMIDITY_OK_bm);
    sensorError = false;
    modbusInputRegisters.gasVP = vapourPressure(modbusInputRegisters.gasTempC, modbusInputRegisters.gasRH);
    modbusInputRegisters.gasAH = absoluteHumidity(modbusInputRegisters.gasTempC, modbusInputRegisters.gasVP);
  }
  
  if (sensorError) {
    systemState.state = STATE_ERROR;
    return false;
  } else if (prevSensorError && systemState.state != STATE_CALIBRATING_O2) {
    systemState.state = STATE_NORMAL;
  }
  return true;
}
bool updateAmbientTemp() {
  static bool sensorError = false;
  bool prevSensorError = sensorError;
  float temperature = ntcAmb.temperature();
  if (isnan(temperature)) {
    setErrorState(STATUS_AMB_TEMP_bp, STATUS_AMB_TEMP_SENSOR_ERROR_bm);
    sensorError = true;
  } else {
    setErrorState(STATUS_AMB_TEMP_bp, STATUS_AMB_TEMP_OK_bm);
    sensorError = false;
  }
  modbusInputRegisters.ambTempC = temperature;

  if (sensorError) {
    systemState.state = STATE_ERROR;
    return false;
  } else if (prevSensorError && systemState.state != STATE_CALIBRATING_O2) {
    systemState.state = STATE_NORMAL;
  }
  return true;
}
bool updateHeaterTemp() {
  static bool sensorError = false;
  bool prevSensorError = sensorError;

  static uint32_t stableCount = 0;
  bool wasUnstable = stableCount < 5 ? true : false;

  float temperature = ntcHeat.temperature();
  
  if (isnan(temperature)) {
    setErrorState(STATUS_HEATER_bp, STATUS_HEATER_SENSOR_ERROR_bm);
    sensorError = true;
  } else if (abs(temperature - heaterCtrl.getSetpoint()) > 0.2) {
    setErrorState(STATUS_HEATER_bp, STATUS_HEATER_TEMP_UNSTABLE_bm);
    systemState.state = STATE_TEMP_UNSTABLE;
    stableCount = 0;
    sensorError = false;
  } else {
    stableCount++;
    if (stableCount >= 5) {
      setErrorState(STATUS_HEATER_bp, STATUS_HEATER_OK_bm);
    } else setErrorState(STATUS_HEATER_bp, STATUS_HEATER_TEMP_UNSTABLE_bm);
    sensorError = false;
  }
  modbusInputRegisters.heatTempC = temperature;

  if (sensorError) {
    systemState.state = STATE_ERROR;
    return false;
  } else if ((prevSensorError || wasUnstable) && stableCount >= 5 && systemState.state != STATE_CALIBRATING_O2) {
    systemState.state = STATE_NORMAL;
  }
  return true;
}
bool updateO2() {
  static bool sensorError = false;
  bool prevSensorError = sensorError;

  modbusInputRegisters.O2percent = O2.readO2(modbusInputRegisters.gasTempC);
  if (modbusInputRegisters.O2percent < 1.0 || isnan(modbusInputRegisters.O2percent)) {
    modbusInputRegisters.O2percent = 0.0;
    setErrorState(STATUS_O2_SENSOR_bp, STATUS_O2_SENSOR_NOT_CONNECTED_bm);
    sensorError = true;
  }
  else if (modbusInputRegisters.O2percent > 25.0) {
    setErrorState(STATUS_O2_SENSOR_bp, STATUS_O2_SENSOR_TOO_HIGH_bm);
    sensorError = true;
  }
  else {
    setErrorState(STATUS_O2_SENSOR_bp, STATUS_O2_SENSOR_OK_bm);
    sensorError = false;
  }

  if (sensorError) {
    systemState.state = STATE_ERROR;
    return false;
  } else if (prevSensorError && systemState.state != STATE_CALIBRATING_O2) {
    systemState.state = STATE_NORMAL;
  }
  return true;
}
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

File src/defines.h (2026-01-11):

#pragma once

#include <Arduino.h>
#include "debug/debug.h"
// Lib includes
#include <wdt_samd21.h>
#include <Adafruit_NeoPixel_ZeroDMA.h>
#include <SensirionI2cSht4x.h>
#include <Wire.h>
#include "SGX_4OX.h"
#include "SGX_INIR2_CD100.h"
#include "NTC_Therm.h"
#include "PID_Control.h"
#include "modbus-rtu-slave.h"

// Pins
#define PIN_VPSU_FB 2
#define PIN_VREF 3
#define PIN_NTC_HEAT 4
#define PIN_NTC_AMB 5
#define PIN_V_O2_SENS 6
#define PIN_RS485_TERM 7
#define PIN_RS485_TX 8
#define PIN_RS485_RX 9
#define PIN_RS485_DE 10
#define PIN_HEAT_PWM 11
#define PIN_LED_DAT 14
#define PIN_GPIO_15 15
#define PIN_UART_CO2_TX 16
#define PIN_UART_CO2_RX 17
#define PIN_GPIO_18 18
#define PIN_GPIO_19 19
#define PIN_I2C_SDA 22
#define PIN_I2C_SCL 23
#define PIN_GPIO_27 27
#define PIN_GPIO_28 28

// Volatge divider constants
#define VPSU_R1 100000
#define VPSU_R2 7500
#define VPSU_V_GAIN (VPSU_R1 + VPSU_R2)/VPSU_R2
#define ADC_MAX 4095.0
#define ADC_VREF_mV  2048.0
#define ADC_mV_PER_LSB ADC_VREF_mV/ADC_MAX
#define VREF_ADC_MULTIPLIER ADC_mV_PER_LSB*VPSU_V_GAIN

// Analog defines
#define NTC_MOVING_AVERAGE_SAMPLES 10
#define NTC_OVERSAMPLING_SAMPLES 10

// Lib Objects
//Adafruit_NeoPixel led(1, PIN_LED_DAT, NEO_GRB + NEO_KHZ800);
Adafruit_NeoPixel_ZeroDMA led(1, PIN_LED_DAT, NEO_GRB + NEO_KHZ800);
SensirionI2cSht4x sht;
SGX40X O2(PIN_V_O2_SENS, 12, 2.048, 100.0, 100.0);
CD100 CO2(Serial2);
NTC_Therm ntcHeat(PIN_NTC_HEAT, 10000.0, 10000.0, 4100.0, true, 12, 2.048);
NTC_Therm ntcAmb(PIN_NTC_AMB, 10000.0, 10000.0, 4100.0, true, 12, 2.048);
PID_Control heaterCtrl(PIN_HEAT_PWM, true);
ModbusRTUSlave modbus(Serial1, PIN_RS485_DE);

// LED colours
#define LED_RED 0xFF0000
#define LED_GREEN 0x00FF00
#define LED_BLUE 0x0000FF
#define LED_YELLOW 0xAAFF00
#define LED_AMBER 0xFFAA00
#define LED_CYAN 0x00FFFF
#define LED_MAGENTA 0xFF00FF
#define LED_WHITE 0xFFFFFF
#define LED_OFF 0x000000

// States and LED colours
#define STATE_NORMAL 0
#define STATE_STARTUP 1
#define STATE_ERROR 2
#define STATE_CALIBRATING_O2 3
#define STATE_TEMP_UNSTABLE 4

#define STATE_NORMAL_COLOUR LED_GREEN
#define STATE_STARTUP_COLOUR LED_MAGENTA
#define STATE_ERROR_COLOUR LED_RED
#define STATE_CALIBRATING_O2_COLOUR LED_BLUE
#define STATE_TEMP_UNSTABLE_COLOUR LED_AMBER

#define STATE_NORMAL_BLINK_Hz 1
#define STATE_STARTUP_BLINK_Hz 1
#define STATE_ERROR_BLINK_Hz 0.5
#define STATE_CALIBRATING_O2_BLINK_Hz 0.5
#define STATE_TEMP_UNSTABLE_BLINK_Hz 0.5

struct sysState {
    uint8_t state;
    uint32_t colour[5] = {  STATE_NORMAL_COLOUR,
                            STATE_STARTUP_COLOUR,
                            STATE_ERROR_COLOUR,
                            STATE_CALIBRATING_O2_COLOUR,
                            STATE_TEMP_UNSTABLE_COLOUR  };
    float blinkHz[5] = {    STATE_NORMAL_BLINK_Hz,
                            STATE_STARTUP_BLINK_Hz,
                            STATE_ERROR_BLINK_Hz,
                            STATE_CALIBRATING_O2_BLINK_Hz,
                            STATE_TEMP_UNSTABLE_BLINK_Hz  };
} systemState;

// staus register definitions
#define STATUS_SYSTEM_bp 0
#define STATUS_O2_SENSOR_bp 4
#define STATUS_CO2_SENSOR_bp 8
#define STATUS_HEATER_bp 12
#define STATUS_GAS_TEMP_HUMIDITY_bp 16
#define STATUS_AMB_TEMP_bp 20
#define STATUS_WDT_RESETS_bp 24

// System status values
#define STATUS_SYSTEM_OK_bm 0x01
#define STATUS_SYSTEM_WDT_RESET_bm 0x02

// O2 sensor status values
#define STATUS_O2_SENSOR_OK_bm 0x01
#define STATUS_O2_SENSOR_TOO_HIGH_bm 0x02
#define STATUS_O2_SENSOR_NOT_CONNECTED_bm 0x04

// CO2 sensor status values
#define STATUS_CO2_SENSOR_OK_bm 0x01
#define STATUS_CO2_SENSOR_NOT_CONNECTED_bm 0x02
#define STATUS_CO2_SENSOR_ERROR_bm 0x04

// Heater status values
#define STATUS_HEATER_OK_bm 0x01
#define STATUS_HEATER_TEMP_UNSTABLE_bm 0x02
#define STATUS_HEATER_SENSOR_ERROR_bm 0x04

// Gas temp and humidity sensor status values
#define STATUS_GAS_TEMP_HUMIDITY_OK_bm 0x01
#define STATUS_GAS_TEMP_HUMIDITY_SENOSR_ERROR_bm 0x02

// Ambient temp sensor status values
#define STATUS_AMB_TEMP_OK_bm 0x01
#define STATUS_AMB_TEMP_SENSOR_ERROR_bm 0x02

// CO2 constants
#define CO2_MAX_DATA_AGE_MS 3000

// EEPROM
#define EEPROM_VERSION_BYTE 0xA0

// Config array structure
struct Config {
    uint32_t wdtTimerResetCounter = 0;
    uint32_t modbusBaudrate = 9600;
    uint16_t modbusConfig = SERIAL_8N1;
    uint8_t modbusSlaveID = 100;
    uint8_t modbus120Rterm = 0;
    float heaterKp = 100.0;
    float heaterKi = 0.5;
    float heaterKd = 0.0;
    float heaterMaxI = 90.0;
    float heaterSetpointC = 30.0;
    float heaterMinAmbientDeltaC = 5.0;
    float o2CalibrationOffset = 0.06;
    float o2CalibrationScale = 0.2;
    int32_t co2CalibrationOffset = 0;
    float co2CalibrationScale = 1.0;
    float ntcAmbOffsetC = 0.0;
    float ntcAmbScale = 1.0;
    float ntcHeatOffsetC = 0.0;
    float ntcHeatScale = 1.0;
};

Config config;
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

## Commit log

2025-12-26 Initial test code for hardware basic tests
    [qtpy_m0.cfg]
2025-12-30 Basic sensor control and reading completed
2026-01-04 Serial buffer bug fix
    [defines.h, main.cpp]
2026-01-09 Switched to DMA Neopixel library, created safeFlush() Serial method to fix sercom lockup issue, added WDT.
    [defines.h, main.cpp]
2026-01-10 Extensive error condition checking added
    [defines.h, main.cpp]
2026-01-10 Documentation added
    [Gas Analyser O2 CO2.PcbDoc, Gas Analyser O2 CO2.PrjPcb, Gas Analyser O2 CO2.SchDoc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]
2026-01-11 Fix struct packing alignment issue
    [defines.h]
2026-01-11 Heater setpoint update bug fix
    [main.cpp]
2026-01-12 Reset stable count after calibration
